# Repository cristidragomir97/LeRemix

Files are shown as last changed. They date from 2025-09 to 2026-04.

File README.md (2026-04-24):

# LLMy (leh·mee)

<p>
  <a href="https://opensource.org/licenses/MIT">
    
  </a>
  <a href="https://docs.ros.org/en/jazzy/">
    
  </a>
  <a href="http://gazebosim.org/">
    
  </a>
</p>

<p align="center">
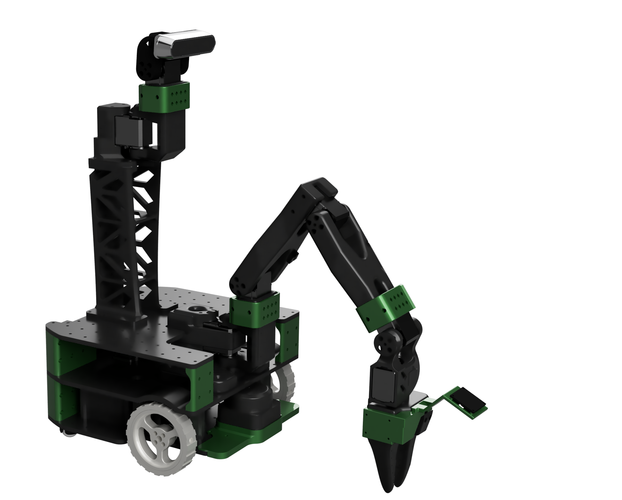
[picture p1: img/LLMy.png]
LLMy Robot
  
</p>

**LLMy** is a fully 3D-printed mobile manipulator built to be affordable, modular and ready to experiment with. 

| Component | Description |
|---|---|
| **Power** | 145W USB-C power bank with dual USB-PD triggers (12V) |
| **Compute** | Almost any SBC or Mini-PC under 75W |
| **Arm + Head** | 7× FEETECH ST3215 bus servos (6-DOF arm + 1-axis tilt) |
| **Drive** | 2× Waveshare DDSM210 direct-drive hub motors (differential) |
| **Bus Bridge** | [Axon](https://github.com/cristidragomir97/axon) — custom RP2350 PCB exposing the half-duplex servo bus, DDSM UART, RS485, CAN, and I²C over USB-CDC |
| **Perception** | RGB-D head camera and UVC wrist camera |
| **Localization** | RPLidar C1 (2D SLAM), wheel encoders, ICM-20948 IMU |

> 📋 **[Full BOM with sourcing links](docs/bom.md)** — includes camera options, SBC recommendations, and alternatives.

## 🏗️ Architecture

LLMy follows a modular ROS2 architecture that separates concerns between simulation, hardware interfaces, control, and user interaction. 

- **Hardware Abstraction**: The `ros2_control` framework provides a clean interface between high-level controllers (MoveIt2, Nav2) and low-level hardware, allowing the same code to run in both simulation and on real hardware.

- **Modular Sensors**: Each sensor system (cameras, IMU, LIDAR) is encapsulated in its own ROS2 package, publishing standardized messages that any application can consume. This makes it easy to swap sensors or add new ones without modifying application code.

- **Layered Control**: The control stack is separated into layers - from the motor manager nodes handling individual bus transactions, through the ros2_control plugin managing the hardware interface, up to high-level motion planning with MoveIt2 and navigation with Nav2.

- **Unified USB Bridge**: A single custom PCB ([Axon](https://github.com/cristidragomir97/axon)) consolidates every bus on the robot (half-duplex servo bus, DDSM UART, LIDAR UART, RS485, CAN, I²C) into one USB composite device. The SBC sees stable `/dev/axon-*` symlinks (via bundled udev rules) and each bus stays independent.

- **Simulation-First Development**: Gazebo integration allows safe development and testing before deploying to hardware. The same launch files and controllers work in both environments, reducing the simulation-to-reality gap.

```mermaid
graph TB

    subgraph "SBC (Jetson / Pi)"
        direction TB
        Control[🎛️ ros2_control]
        ControlPlugin[📦 llmy_control_plugin]
        St3215[📦 st3215_manager]
        Ddsm210[📦 ddsm210_manager]
        Nav[📦 llmy_nav · Nav2]
        Slam[📦 llmy_slam · slam_toolbox]
        MoveIt[📦 llmy_moveit · MoveIt 2]
        MCP[📦 llmy_mcp · MCP server]
        Teleop[📦 llmy_teleop_xbox]
        CameraNode[📦 llmy_camera]
        ImuNode[📦 llmy_imu]
        LidarNode[📦 rplidar]
    end

    subgraph "Axon USB Bridge (RP2350)"
        direction TB
        CdcMotor[CDC · half-duplex servo bus]
        CdcUart0[CDC · UART0 · DDSM bus]
        CdcUart1[CDC · UART1 · LIDAR]
    end

    subgraph "Actuators"
        Arm[6-DOF Arm · 6× ST3215]
        Tilt[Head Tilt · 1× ST3215]
        Wheels[Differential Drive · 2× DDSM210]
    end

    subgraph "Sensors"
        LIDAR[📏 RPLidar C1]
        HeadCamera[📷 RealSense D435i]
        WristCamera[📷 UVC wrist cam]
        IMU[📐 ICM-20948]
    end

    Teleop --> Control
    Nav --> Control
    MoveIt --> Control
    MCP <--> Control
    Slam --> Nav

    Control --> ControlPlugin
    ControlPlugin --> St3215
    ControlPlugin --> Ddsm210

    St3215 --> CdcMotor
    Ddsm210 --> CdcUart0

    CdcMotor --> Arm
    CdcMotor --> Tilt
    CdcUart0 --> Wheels

    LIDAR --> CdcUart1
    CdcUart1 --> LidarNode
    HeadCamera --> CameraNode
    WristCamera --> CameraNode
    IMU --> ImuNode

```

--- 

### 📦 ROS Packages

**Core Packages:**
- [**llmy_description**](ros/src/llmy_description/) - Robot URDF model with accurate kinematics and collision meshes
- [**llmy_control_plugin**](ros/src/llmy_control_plugin/) - ros2_control SystemInterface that bridges controllers to the motor-manager nodes over ROS topics
- [**llmy_control**](ros/src/llmy_control/) - Controller parameters, ros2_control configurations, hw/sim launch files
- [**st3215_manager**](ros/src/st3215_manager/) - Driver for FEETECH ST3215 servo groups (arm + head)
- [**ddsm210_manager**](ros/src/ddsm210_manager/) - Driver for Waveshare DDSM210 direct-drive wheel motors
- [**llmy_teleop_xbox**](ros/src/llmy_teleop_xbox/) - Xbox controller interface for manual driving + arm
- [**llmy_bringup**](ros/src/llmy_bringup/) - Top-level hardware bringup launch

**Navigation & SLAM:**
- [**llmy_nav**](ros/src/llmy_nav/) - Nav2 configuration and navigation mode management (mapping, navigation, mapfree, slam_nav)
- [**llmy_slam**](ros/src/llmy_slam/) - slam_toolbox configs for mapping and online SLAM

**Manipulation:**
- [**llmy_moveit**](ros/src/llmy_moveit/) - MoveIt 2 configuration for the 6-DOF arm (OMPL planning, KDL kinematics)

**Sensor & Vision:**
- [**llmy_camera**](ros/src/llmy_camera/) - RGB-D camera integration with depth-to-laser conversion
- [**llmy_imu**](ros/src/llmy_imu/) - IMU sensor fusion for orientation and navigation

**AI & Integration:**
- [**llmy_mcp**](ros/src/llmy_mcp/) - MCP (Model Context Protocol) server exposing ROS2 interfaces to LLMs

**Simulation:**
- [**llmy_gazebo**](ros/src/llmy_gazebo/) - Configurations and launch files for Gazebo simulation

**📋 [Detailed Package Documentation](docs/packages.md)**

## 🚀 Quick Start

### 🎮 Simulation (Fastest Way to Try LLMy!)

Get the robot running in Gazebo simulation in just a few commands:

```bash
# Clone and build the workspace
git clone https://github.com/cristidragomir97/llmy llmy_ws
cd llmy_ws/ros
vcs import src < repos.vcs
rosdep install --from-paths src --ignore-src -r -y
colcon build --symlink-install
source install/setup.bash

# Launch Gazebo simulation with controllers
ros2 launch llmy_gazebo gazebo.launch.py
```

The robot will spawn in Gazebo with all controllers active.

In a new terminal, start Xbox controller teleoperation:

```bash
ros2 launch llmy_teleop_xbox teleop_xbox.launch.py
```

**🎮 Xbox Controller Mapping:**
- **🏎️ Base Movement:** Right stick (forward/back + rotate)
- **🦾 Arm Control:**
  - **Joint 1:** RB (+) / LB (−)
  - **Joint 2:** RT (+) / LT (−)
  - **Joint 3:** Y (+) / A (−)
  - **Joint 4:** B (+) / X (−)
  - **Joint 5:** Start (+) / Back (−)
  - **Joint 6:** Right-stick click (+) / Left-stick click (−)
- **📷 Camera Tilt:** D-pad up/down

### 🏭 Hardware (via Forge)

LLMy on the real robot is deployed via [**Forge**](https://github.com/cristidragomir97/robocore-forge) — a lightweight deployment tool that takes a declarative `robot.yaml`, builds one Docker image per ROS component, and wires them together with a generated `docker-compose.<host>.yaml`. Each package (motion, SLAM, nav, camera, IMU, LIDAR, MCP, teleop, etc.) runs in its own container and communicates over a shared [Zenoh](https://zenoh.io/) router, so any single component can be rebuilt, restarted, or swapped without touching the rest.

The flow:

1. Edit `robot.yaml` — declare components, the packages each includes, the hardware devices each needs mounted, and the host it runs on.
2. `forge build` — one image per component, ready to push.
3. `forge deploy` — copies the generated compose file to the target and runs `docker compose up -d`.

Everything under `ros/src/` is plain ROS 2; Forge is just the packaging layer. You can bypass it entirely and run `colcon build` + `ros2 launch` on the SBC if you prefer bare metal.

### 📐 First-time calibration

Before commanding the arm, the servo encoder zeros need to match the URDF's zero pose. Walk through:

**📖 [Arm calibration guide](docs/arm-calibration.md)**

For general setup and troubleshooting:

**📖 [Getting Started Guide](docs/getting-started.md)**

---

--- 
## 🙏 Credits & Acknowledgments
This project stands on the shoulders of incredible open-source work:

- **[LeRobot Team](https://github.com/huggingface/lerobot)** - For pioneering accessible robotics and AI integration
- **[SIGRobotics-UIUC](https://github.com/SIGRobotics-UIUC)** - For their foundational work on LeKiwi
- **[Pavan Vishwanath](https://github.com/Pavankv92)** - ROS2 package development for [LeRobot SO-ARM101](https://github.com/Pavankv92/lerobot_ws)
- **[Gaotian Wang](https://github.com/Vector-Wangel/XLeRobot)** - For his amazing work on XLeRobot. Also for being kind enough to publish the STEP files for his robot upon request, files that were used to create the camera tower for LLMy. 

---
<div align="center">

<strong>⭐ Star this repo if LLMy helped you build something awesome! ⭐</strong>
</div>

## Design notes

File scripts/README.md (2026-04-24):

# LLMy Setup Scripts

Utility scripts for configuring and calibrating your LLMy robot.

## Scripts Overview

### 1. `set_servo_id.py` - Servo ID Configuration

Interactive tool for setting FEETECH STS3215 servo IDs one by one.

**Usage:**

```bash
# List all servos on the bus with telemetry
python3 set_servo_id.py --list

# Interactive mode - configure servos one by one
python3 set_servo_id.py

# Direct ID change
python3 set_servo_id.py --old-id 1 --new-id 5

# Custom serial port
python3 set_servo_id.py --port /dev/ttyACM0 --list
```

**LLMy ID Assignments:**
- Base (locomotion): IDs **1, 2, 3**
- Arm (manipulator): IDs **4, 5, 6, 7, 8, 9**
- Head (pan & tilt): IDs **10, 11**

**Workflow:**
1. Connect servos **one at a time** to avoid ID conflicts
2. Run interactive mode: `python3 set_servo_id.py`
3. For each servo:
   - Connect it to the bus
   - Script detects current ID
   - Enter desired new ID
   - Disconnect and connect next servo
4. Final verification scan shows all configured servos

---

### 2. `calibrate_arm.py` - Arm Calibration

Calibrates arm joint zero positions and movement limits.

**Usage:**

```bash
# Basic calibration (will prompt for save)
python3 calibrate_arm.py

# Auto-save to config file
python3 calibrate_arm.py --config ~/llmy_ws/ros/src/llmy_servo_manager/config/servo_manager.yaml

# Custom serial port
python3 calibrate_arm.py --port /dev/ttyUSB0
```

**⚠️ IMPORTANT:** Stop all ROS2 nodes before running calibration!

```bash
# Kill any running servo manager nodes
pkill -f servo_manager
```

**Calibration Process:**

1. **Zero Position Setup:**
   - Position arm fully erect (vertical)
   - Close gripper completely
   - Center wrist rotation
   - Script records zero positions

2. **Joint Limit Calibration:**
   - For each of 6 arm joints:
     - Move joint to minimum position → record
     - Move joint to maximum position → record
   - Script validates and saves limits

3. **Verification:**
   - Arm returns to zero position
   - Summary table shows all calibration data
   - Option to save to YAML config

**Output Example:**
```
┌─────────────────────────┬──────┬──────────┬─────────┬─────────┐
│ Joint                   │  ID  │ Zero Pos │ Min Pos │ Max Pos │
├─────────────────────────┼──────┼──────────┼─────────┼─────────┤
│ Joint 1 (Base Rotation) │   4  │  2048    │   512   │  3584   │
│ Joint 2 (Shoulder)      │   5  │  2048    │   768   │  3328   │
...
```

**What Gets Saved:**

The calibration tool updates `servo_manager.yaml` with:
- `arm_zero_positions`: Reference position for each joint (6 values)
- `arm_min_limits`: Minimum safe position in ticks (6 values)
- `arm_max_limits`: Maximum safe position in ticks (6 values)

These limits are automatically enforced by the servo manager to prevent damage.

---

## Prerequisites

### Hardware Setup
- Robot powered on (12V to servos)
- Serial connection established (USB or UART)
- Correct serial port identified

### Software Requirements
```bash
# Install st3215 Python library
pip install st3215

# Install PyYAML for config management
pip install pyyaml
```

### Permissions
```bash
# Add your user to dialout group for serial access
sudo usermod -a -G dialout $USER
# Log out and back in for changes to take effect
```

---

## Common Serial Ports

| Platform | Port | Description |
|---|---|---|
| Raspberry Pi | `/dev/ttyUSB0` | USB adapter |
| Jetson Nano/Orin | `/dev/ttyTHS1` | Hardware UART |
| Generic Linux | `/dev/ttyACM0` | USB CDC adapter |
| Waveshare adapter | `/dev/ttyUSB0` | FT232 USB-Serial |

**Find your port:**
```bash
# List all serial devices
ls /dev/tty{USB,ACM,THS}* 2>/dev/null

# Monitor kernel messages when plugging in
dmesg | tail
```

---

## Workflow: Full Robot Setup

**Complete setup from scratch:**

```bash
# 1. Set all servo IDs (connect one at a time)
cd ~/llmy_ws/scripts
python3 set_servo_id.py

# 2. Verify all servos are detected
python3 set_servo_id.py --list

# 3. Calibrate arm joints
python3 calibrate_arm.py --config ../ros/src/llmy_servo_manager/config/servo_manager.yaml

# 4. Build and launch ROS workspace
cd ~/llmy_ws/ros
colcon build
source install/setup.bash
ros2 launch llmy_bringup bringup_robot.launch.py
```

---

## Troubleshooting

### Script can't connect to servos
```bash
# Check port exists
ls -l /dev/ttyUSB0

# Check permissions
groups  # Should show 'dialout'

# Try different baud rates
python3 set_servo_id.py --baud 115200
```

### Servo not responding during calibration
- Ensure 12V power supply is connected
- Check servo cables are properly seated
- Verify servo ID matches expected value
- Try power cycling the servo

### Calibration data not saving
- Verify config file path is correct
- Check file permissions (must be writable)
- Review backup file (.backup) for changes
- Manually inspect YAML syntax

### ROS node conflicts
```bash
# Kill all servo-related processes
pkill -f servo_manager
pkill -f llmy

# Verify no nodes running
ros2 node list
```

---

## Advanced Usage

### Batch ID Configuration
```bash
# Script for setting multiple servos
for id in {1..11}; do
  echo "Connect servo for ID $id and press enter..."
  read
  python3 set_servo_id.py --old-id 1 --new-id $id
done
```

### Custom Calibration Workflow
```python
# Manual calibration via Python API
from st3215 import ST3215

servo = ST3215('/dev/ttyUSB0')
pos = servo.ReadPosition(4)  # Read joint 1 position
print(f"Current position: {pos} ticks")
```

### Verify Limits Are Enforced
```bash
# After calibration, test limit enforcement
ros2 topic pub /motor_manager/arm_cmd std_msgs/msg/Float64MultiArray "data: [10.0, 0, 0, 0, 0, 0]"
# Joint should clamp to max limit, not attempt invalid position
```

---

## Support

For issues or questions:
- GitHub Issues: https://github.com/cristidragomir97/llmy/issues
- Documentation: [docs/getting-started.md](../docs/getting-started.md)

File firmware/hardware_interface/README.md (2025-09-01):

# Simple MicroROS Servo Driver

A simplified, barebones version of the microros_servo_driver with only essential functionality.

## Features

- ✅ MicroROS communication
- ✅ Servo control (arm and base servos)
- ✅ Joint state publishing
- ✅ Serial debugging output
- ❌ No display/OLED support
- ❌ No button input handling
- ❌ No watchdog functionality
- ❌ Minimal dependencies

## Hardware Requirements

- ESP32 development board
- Servo communication via GPIO 18 (RX) and GPIO 19 (TX)
- Serial connection for debugging and MicroROS communication

## Configuration

All servo calibration and hardware settings are defined in `src/config.h`.

## Build and Upload

This project uses PlatformIO:

```bash
# Build the project
pio run

# Upload to ESP32
pio run --target upload

# Monitor serial output
pio device monitor
```

## Dependencies

- MicroROS PlatformIO library
- SCServo library for servo communication

## Usage

1. Flash the firmware to your ESP32
2. Connect via serial at 115200 baud
3. The device will automatically connect to MicroROS and start listening for commands
4. Servos are enabled by default

## Topics

- `/esp32/base_cmd` - Base motor commands (Float64MultiArray)
- `/esp32/arm_cmd` - Arm joint commands (Float64MultiArray) 
- `/esp32/joint_states` - Joint state feedback (JointState)

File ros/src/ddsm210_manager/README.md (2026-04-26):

# ddsm210_manager

ROS2 driver for Waveshare DDSM210 direct drive servo motors. Includes a from-scratch serial protocol implementation — no external motor library required.

## Quick Start

```bash
colcon build --packages-select ddsm210_manager

ros2 launch ddsm210_manager ddsm210.launch.py

# Custom config
ros2 launch ddsm210_manager ddsm210.launch.py config_file:=/path/to/config.yaml
```

## Hardware

- **Motor**: Waveshare DDSM210 (integrated brushless motor + encoder + FOC driver)
- **Interface**: UART (TX, RX, GND, VCC)
- **Baud**: 115200, 8N1
- **Voltage**: 11-22V DC
- **Speed**: -210..210 RPM
- **Encoder**: 4096 resolution (relative), 65536 ticks/rev (position feedback)

## Protocol

The driver implements the full DDSM210 UART protocol (10-byte frames, CRC-8/MAXIM):

| Protocol | Command | Description |
|---|---|---|
| 1 (0x64) | Drive | Set velocity/position, get speed+position+temp feedback |
| 2 (0x74) | Odometry | Get mileage laps (continuous) + absolute position |
| 3 (0xA0) | Set Mode | Open loop (0x00), velocity loop (0x02), position loop (0x03) |
| 4 | Set ID | Change motor ID (send 5x, one motor on bus) |
| 5 (0x75) | Query Mode | Get current operating mode |

## Wiring: Multi-Motor Setup

The DDSM210 uses separate TX/RX UART lines. When connecting multiple motors, their TX outputs will conflict if wired together directly. Two options:

**Option 1 — Separate ports (recommended for direct wiring):**
Each motor gets its own USB-to-UART adapter. Configure `ports` with one entry per motor:
```yaml
ports: ["/dev/ttyUSB0", "/dev/ttyUSB1"]
motor_ids: [1, 2]
```

**Option 2 — Shared bus (requires AND gates):**
Use a bus board like the Waveshare DDSM Driver HAT, which combines motor TX lines through AND gates (SN74LVC1G08). Configure a single port:
```yaml
ports: ["/dev/ttyUSB0"]
motor_ids: [1, 2]
```

## Configuration

| Parameter | Type | Default | Description |
|---|---|---|---|
| `ports` | string[] | `["/dev/ttyUSB0"]` | Serial port(s) — one per motor, or one shared by all |
| `baud` | int | `115200` | Baud rate |
| `command_rate` | float | `50.0` | Command send rate (Hz) |
| `telemetry_rate` | float | `50.0` | JointState publish rate (Hz) |
| `joint_states_topic` | string | `/motor_manager/joint_states` | JointState output topic |
| `command_topic` | string | `/motor_manager/base_cmd` | Float64MultiArray command input topic |
| `total_joints` | int | `0` | JointState array size (0 = auto from state_indices) |
| `mode` | string | `velocity` | `velocity` or `position` |
| `accel_time` | int | `0` | Acceleration per 1 RPM in 0.1ms units |
| `motor_ids` | int[] | `[1, 2]` | Motor IDs on the bus |
| `joint_names` | string[] | `[right_wheel_joint, left_wheel_joint]` | Joint names for JointState |
| `direction` | int[] | `[1, -1]` | Per-motor direction multiplier |
| `command_indices` | int[] | `[0, 1]` | Which indices to read from incoming command array |
| `state_indices` | int[] | `[0, 1]` | Which indices to write in JointState arrays |
| `speed_scale` | float | `1.0` | Multiplier applied to incoming velocity commands |

## Sharing the JointState Topic

This package publishes JointState to the same topic as the `st3215_servo_manager`. Each package fills in its own `state_indices` slots:

```
DDSM210 (wheels):     state_indices: [0, 1]
ST3215 (arm+camera):  state_indices: [2, 3, 4, 5, 6, 7, 8]
```

Both publish to `/motor_manager/joint_states`. Consumers match by joint name.

## Low-Level API

The `ddsm210.py` module can be used standalone without ROS:

```python
from ddsm210_manager.ddsm210 import DDSM210, MODE_VELOCITY

motor = DDSM210("/dev/ttyUSB0")
motor.set_mode(1, MODE_VELOCITY)
motor.set_velocity(1, 500)   # 50 RPM
motor.brake(1)
odom = motor.get_odometry(1) # {'mileage_laps': ..., 'position': ..., 'error_code': ...}
motor.close()
```

## Interactive Terminal

Test motors without ROS using the built-in terminal:

```bash
# Single port
python3 scripts/test_motor.py --port /dev/ttyUSB0

# Two ports (one per motor)
python3 scripts/test_motor.py --port /dev/ttyUSB0 --port /dev/ttyUSB1
```

Commands: `scan`, `ping`, `speed`, `brake`, `odom`, `mode`, `pos`, `set_id`, `query_id`, `ports`, `quit`.

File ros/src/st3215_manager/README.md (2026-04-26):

# st3215_manager

Generic, config-driven ROS2 driver for FEETECH ST3215 servo motors. Define motor groups in YAML — no code changes needed to add motors or support a new robot.

## Quick Start

```bash
# Build
colcon build --packages-select st3215_manager

# Launch with default config
ros2 launch st3215_manager servo_manager.launch.py

# Launch with a custom config
ros2 launch st3215_manager servo_manager.launch.py \
  config_file:=/path/to/your/config.yaml
```

## Configuration

All configuration lives in a single YAML file. See `config/servo_manager.yaml` for the LLMy default and `config/so101_arm.yaml` for a standalone SO-101 arm example.

### Global Parameters

| Parameter | Type | Default | Description |
|---|---|---|---|
| `port` | string | `/dev/ttyTHS1` | Serial port for the Feetech bus |
| `baud` | int | `1000000` | Baud rate |
| `ticks_per_rev` | int | `4096` | Encoder ticks per revolution |
| `telemetry_rate` | float | `50.0` | Joint state publish rate (Hz) |
| `joint_states_topic` | string | `/motor_manager/joint_states` | Topic for JointState output |
| `total_joints` | int | `0` | Size of JointState arrays. Set to `0` to auto-calculate from highest `state_index + 1` |
| `brake_method` | string | `torque_disable` | `torque_disable`, `velocity_ramp`, or `position_brake` |
| `velocity_ramp_time` | float | `0.1` | Ramp time for velocity_ramp brake (s) |
| `brake_acceleration` | int | `100` | Acceleration for position_brake method |
| `motor_telemetry_enable` | bool | `false` | Publish per-motor current/voltage/load/temperature |
| `motor_telemetry_rate` | float | `10.0` | Per-motor telemetry rate (Hz) |
| `test_on_startup` | bool | `false` | Run motor test sequences on startup |
| `group_names` | string[] | `["base"]` | List of motor group names to load |

### Motor Group Parameters

Each entry in `group_names` becomes a parameter prefix. For a group named `arm`, the parameters are `arm.enable`, `arm.mode`, etc.

| Parameter | Type | Default | Description |
|---|---|---|---|
| `<name>.enable` | bool | `true` | Enable this group |
| `<name>.mode` | string | `velocity` | `velocity` or `position` |
| `<name>.topic` | string | `/motor_manager/<name>_cmd` | ROS topic to subscribe for commands |
| `<name>.motor_ids` | int[] | `[]` | ST3215 motor IDs on the bus |
| `<name>.joint_names` | string[] | `[]` | Joint names for JointState messages |
| `<name>.direction` | int[] | `[]` | Per-motor direction multiplier (`1` or `-1`) |
| `<name>.command_indices` | int[] | `[]` | Which indices in the incoming `Float64MultiArray` to read from |
| `<name>.state_indices` | int[] | `[]` | Which indices in the outgoing `JointState` arrays to write to |
| `<name>.speed_scale` | float | `1.0` | Speed multiplier applied to incoming commands |
| `<name>.accel` | int[] | `[]` | Per-motor acceleration (0-255, lower = smoother) |
| `<name>.unwrap_position` | bool | `false` | Track continuous rotation (needed for wheels/odometry) |
| `<name>.position_speed` | int | `200` | Base speed for position-mode MoveTo commands |
| `<name>.position_accel` | int | `200` | Base accel for position-mode MoveTo commands |

All per-motor arrays (`motor_ids`, `joint_names`, `direction`, `command_indices`, `state_indices`, `accel`) must have the same length.

### Index Mapping

`command_indices` and `state_indices` decouple the motor ordering from message layout:

- **`command_indices`**: Motor `i` reads its command from `msg.data[command_indices[i]]`. This allows the incoming array to contain joints from other packages, or to reorder joints without changing motor wiring.

- **`state_indices`**: Motor `i` writes its state to `JointState.position[state_indices[i]]`. This lets multiple packages publish to the same topic with non-overlapping indices.

#### Example: Shared topic with another motor driver

If a DSSM210 driver handles wheels at indices 0-1, and this package handles the arm at indices 2-7:

```yaml
total_joints: 8   # wheels (0,1) + arm (2-7)

arm:
  motor_ids: [3, 4, 5, 6, 7, 8]
  command_indices: [0, 1, 2, 3, 4, 5]   # arm topic only has arm joints
  state_indices: [2, 3, 4, 5, 6, 7]     # slots 0-1 reserved for wheels
```

The DSSM210 package would publish wheels at indices 0-1 on the same `joint_states_topic`. Consumers match by joint name, and the fixed indices ensure a predictable array layout.

## Topics

### Subscribed (one per enabled group)

Configured via `<group>.topic`. Expects `std_msgs/Float64MultiArray`.

### Published

| Topic | Type | Description |
|---|---|---|
| `<joint_states_topic>` | `sensor_msgs/JointState` | Joint positions and velocities |
| `/motor_telemetry/<joint_name>/current` | `std_msgs/Float32` | Motor current (mA) |
| `/motor_telemetry/<joint_name>/voltage` | `std_msgs/Float32` | Motor voltage (V) |
| `/motor_telemetry/<joint_name>/load` | `std_msgs/Float32` | Motor load (%) |
| `/motor_telemetry/<joint_name>/temperature` | `std_msgs/Int32` | Motor temperature (C) |

Motor telemetry topics are only created when `motor_telemetry_enable: true`.

## Adding a New Robot

1. Copy `config/so101_arm.yaml` as a starting point
2. Set `port` to your serial device
3. Define your motor groups with IDs, joint names, and indices
4. Launch with `config_file:=/path/to/your/config.yaml`

No code changes required.

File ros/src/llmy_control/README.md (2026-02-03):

# llmy_control

Controller configurations and launch files for the LLMy robot's motion subsystem. Manages differential drive, 6-DOF arm, and pan-tilt head through ros2_control.

## Launch Files

| Launch File | Description |
|---|---|
| `motion.launch.py` | Main entry point — launches servo manager + control stack |
| `control_stack.launch.py` | Robot state publisher, controller manager, controller spawners, twist_mux |
| `base_systems.launch.py` | Servo manager for low-level motor communication |

```bash
# Full motion subsystem
ros2 launch llmy_control motion.launch.py

# Control stack only (servo manager already running)
ros2 launch llmy_control control_stack.launch.py
```

## Config Files

| File | Description |
|---|---|
| `controllers.hw.yaml` | Hardware controller definitions (50Hz, real hardware) |
| `controllers.sim.yaml` | Simulation controller definitions (100Hz, sim time) |
| `twist_mux.yaml` | Velocity multiplexer — xbox (pri 50), mcp (pri 30), nav (pri 10) |
| `ros2_control_bridge.yaml` | Hardware interface plugin config for servo_manager topics |

## Controllers

| Controller | Type | State |
|---|---|---|
| `joint_state_broadcaster` | JointStateBroadcaster | Active |
| `diff_drive_controller` | DiffDriveController | Active |
| `arm_controller` | JointGroupPositionController | Active |
| `arm_trajectory_controller` | JointTrajectoryController | Inactive (for MoveIt) |
| `head_controller` | JointGroupPositionController | Active |

Switch to trajectory control for MoveIt:
```bash
ros2 control switch_controller --activate arm_trajectory_controller --deactivate arm_controller
```

## URDF

`urdf/LLMy.hardware.xacro` defines the ros2_control hardware interface using the `llmy_control_plugin/ROS2ControlBridge` plugin, which communicates with the servo manager via ROS topics.

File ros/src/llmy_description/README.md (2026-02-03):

# llmy_description

Complete URDF/Xacro robot model for the LLMy mobile manipulator. Provides the "digital twin" used by all other packages for visualization, simulation, and control.

## Robot Structure

- **Base**: Differential drive with 2 powered wheels + 2 passive casters
- **Arm**: 6-DOF (joints 1-6) — base rotation, shoulder, elbow, two wrist joints, gripper
- **Head**: Pan-tilt camera mount with 2 servos
- **Sensors**: RealSense RGB-D (head), USB camera (wrist), RPLidar, IMU

## Launch Files

```bash
# Visualize the robot model in RViz (standalone)
ros2 launch llmy_description display.launch.py

# Spawn in Gazebo (usually called by llmy_gazebo instead)
ros2 launch llmy_description gazebo.launch.py
```

## Key Files

| File | Description |
|---|---|
| `urdf/LLMy.xacro` | Main robot model — all links, joints, and sensor frames |
| `urdf/materials.xacro` | Material definitions |
| `urdf/LLMy.gazebo` | Gazebo-specific physics and sensor plugins |
| `urdf/LLMy.ros2control` | ros2_control interfaces for simulation |
| `meshes/*.stl` | 48 STL mesh files for visualization and collision |
| `config/display.rviz` | RViz visualization preset |

## Xacro Arguments

| Argument | Default | Description |
|---|---|---|
| `use_sim` | `false` | Load Gazebo ros2_control plugin when `true`, hardware plugin when `false` |

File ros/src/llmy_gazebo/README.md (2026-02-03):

# llmy_gazebo

Gazebo Harmonic simulation environment for the LLMy robot. Spawns the robot with all controllers, sensor bridges, and a furnished apartment world.

## Launch

```bash
# Launch simulation (default: sticky_floor apartment world)
ros2 launch llmy_gazebo gazebo.launch.py

# Empty world
ros2 launch llmy_gazebo gazebo.launch.py world:=empty.sdf
```

## What Gets Launched

1. Robot URDF loaded via xacro (`use_sim:=true`)
2. Gazebo simulation with world file
3. ROS-Gazebo bridges for sensors (lidar, IMU, cameras, clock)
4. Controller spawners: `joint_state_broadcaster`, `diff_drive_controller`, `arm_controller`, `head_controller`
5. `arm_trajectory_controller` loaded inactive (for MoveIt)
6. `twist_mux` for velocity command arbitration

## World Files

| World | Description |
|---|---|
| `sticky_floor.world` | Furnished apartment (~15x12m) with walls, furniture, and obstacles |
| `empty.sdf` | Minimal ground plane with lighting |

## Bridged Topics

| Topic | Type | Direction |
|---|---|---|
| `/scan` | LaserScan | Gazebo -> ROS |
| `/sensors/imu` | Imu | Gazebo -> ROS |
| `/head_camera/rgb/*` | Image + CameraInfo | Gazebo -> ROS |
| `/head_camera/depth/*` | Image + CameraInfo | Gazebo -> ROS |
| `/wrist_camera/rgb/*` | Image + CameraInfo | Gazebo -> ROS |
| `/clock` | Clock | Gazebo -> ROS |

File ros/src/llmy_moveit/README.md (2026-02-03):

# llmy_moveit

MoveIt 2 configuration for the LLMy robot's 6-DOF arm (SO-ARM101) and gripper. Provides collision-free trajectory planning, inverse kinematics, and integration with the ros2_control trajectory controller.

## Launch

```bash
# Hardware
ros2 launch llmy_moveit moveit.launch.py

# Simulation
ros2 launch llmy_moveit moveit.launch.py use_sim_time:=true

# Without RViz
ros2 launch llmy_moveit moveit.launch.py launch_rviz:=false
```

## Prerequisites

The control stack must already be running. MoveIt uses `arm_trajectory_controller`, which is loaded inactive by default. Activate it:

```bash
ros2 control switch_controller --activate arm_trajectory_controller --deactivate arm_controller
```

## Planning Groups

| Group | Joints | Description |
|---|---|---|
| `arm` | 1, 2, 3, 4, 5 | Kinematic chain from base to gripper |
| `gripper` | 6 | Gripper open/close |

## Named Poses

| Pose | Description |
|---|---|
| `home` | All joints at zero |
| `open` | Gripper fully open |
| `closed` | Gripper closed |

## Config Files

| File | Description |
|---|---|
| `llmy.srdf` | Planning groups, named poses, collision disable pairs |
| `kinematics.yaml` | KDL solver (0.005 resolution, 0.05s timeout) |
| `joint_limits.yaml` | Velocity/acceleration limits and scaling factors |
| `ompl_planning.yaml` | OMPL planners: RRTConnect, RRT, PRM |
| `moveit_controllers.yaml` | Maps MoveIt to ros2_control controllers |

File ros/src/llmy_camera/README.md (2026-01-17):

# llmy_camera

Camera integration package for the LLMy robot, providing both a head-mounted RealSense RGB-D camera and a wrist-mounted USB camera with compressed image transport and laser scan conversion capabilities.

## Overview

The llmy_camera package manages two camera systems:
- **Head Camera**: Intel RealSense RGB-D camera (D435i, D455, etc.) mounted on the pan/tilt head
- **Wrist Camera**: USB camera (640x480) mounted on the end-effector for close-up manipulation tasks

## Launch Files

### `camera.launch.py`

Main launch file that brings up both camera systems with full feature set:

**Components:**
- RealSense RGB-D camera (head_camera namespace)
- USB wrist camera (wrist_camera namespace)
- Compressed image transport for both cameras
- Depth-to-laser-scan conversion for navigation

```bash
# Launch both cameras with all features
ros2 launch llmy_camera camera.launch.py

# Launch without wrist camera
ros2 launch llmy_camera camera.launch.py enable_wrist_camera:=false

# Launch without laser scan conversion
ros2 launch llmy_camera camera.launch.py enable_laser_scan:=false

# Disable compressed transport
ros2 launch llmy_camera camera.launch.py enable_compressed:=false
```

### `realsense_only.launch.py`

Minimal launch file for RealSense camera only (no wrist camera, no laser scan, no compression):

```bash
# Launch only RealSense camera
ros2 launch llmy_camera realsense_only.launch.py

# Specify device type
ros2 launch llmy_camera realsense_only.launch.py device_type:=d435i
```

## Launch Arguments

### `camera.launch.py` Arguments

| Argument | Default | Description |
|---|---|---|
| `camera_name` | `head_camera` | RealSense camera name |
| `device_type` | `` | RealSense device type (auto-detect if empty) |
| `enable_wrist_camera` | `true` | Enable USB wrist camera |
| `wrist_camera_device` | `/dev/video0` | Video device path for wrist camera |
| `enable_compressed` | `true` | Enable compressed image transport |
| `enable_laser_scan` | `true` | Enable depth to laser scan conversion |
| `laser_scan_min_height` | `-0.5` | Minimum height for laser scan slice (m) |
| `laser_scan_max_height` | `0.5` | Maximum height for laser scan slice (m) |
| `laser_scan_angle_min` | `-1.57` | Minimum scan angle (-90°) |
| `laser_scan_angle_max` | `1.57` | Maximum scan angle (+90°) |
| `laser_scan_angle_increment` | `0.005` | Angular resolution |
| `laser_scan_range_min` | `0.2` | Minimum range (m) |
| `laser_scan_range_max` | `10.0` | Maximum range (m) |

### `realsense_only.launch.py` Arguments

| Argument | Default | Description |
|---|---|---|
| `camera_name` | `camera` | RealSense camera name |
| `device_type` | `d435i` | RealSense device type |

## Topics Published

### Head Camera (RealSense)

**Color Stream:**
- `/head_camera/head_camera/color/image_raw` - Raw color image (640x480@30Hz)
- `/head_camera/head_camera/color/image_compressed` - Compressed color image (JPEG)
- `/head_camera/head_camera/color/camera_info` - Camera calibration

**Depth Stream:**
- `/head_camera/head_camera/depth/image_rect_raw` - Rectified depth image
- `/head_camera/head_camera/depth/camera_info` - Depth camera calibration

**Laser Scan:**
- `/scan` - 2D laser scan converted from depth (for navigation)

### Wrist Camera (USB)

- `/wrist_camera/image_raw` - Raw wrist camera image (640x480@30Hz)
- `/wrist_camera/image_compressed` - Compressed wrist image (JPEG)
- `/wrist_camera/camera_info` - Camera calibration

## Supported Hardware

### RealSense Cameras
- Intel RealSense D435i (recommended)
- Intel RealSense D455
- Intel RealSense L515
- Other RealSense RGB-D cameras

### Wrist Camera
- Any UVC-compatible USB camera
- Default: 640x480@30fps, MJPEG format

## Usage Examples

### View Camera Streams

```bash
# View head camera color stream
ros2 run rqt_image_view rqt_image_view /head_camera/head_camera/color/image_raw

# View head camera depth
ros2 run rqt_image_view rqt_image_view /head_camera/head_camera/depth/image_rect_raw

# View wrist camera
ros2 run rqt_image_view rqt_image_view /wrist_camera/image_raw

# View compressed images (bandwidth efficient)
ros2 run rqt_image_view rqt_image_view /head_camera/head_camera/color/image_compressed/compressed
ros2 run rqt_image_view rqt_image_view /wrist_camera/image_compressed/compressed
```

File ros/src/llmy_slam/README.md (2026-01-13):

# llmy_slam

SLAM (Simultaneous Localization and Mapping) integration for the LLMy robot using [slam_toolbox](https://github.com/SteveMacenski/slam_toolbox).

This package provides custom launch files and configurations specifically tailored for the LLMy robot's hardware setup.

## Overview

This package wraps slam_toolbox with LLMy-specific configurations for:
- **Sensor input**: RPLidar on `/scan` topic
- **Odometry**: Omnidirectional controller publishing `/omnidirectional_controller/odom` and TF `odom` → `base_link`
- **Base frame**: `base_link`
- **Map frame**: `map`

## Prerequisites

1. **Install slam_toolbox**:
   ```bash
   sudo apt install ros-${ROS_DISTRO}-slam-toolbox
   ```

2. **Ensure RPLidar is publishing** on `/scan` topic:
   - Enable RPLidar in your bringup configuration
   - Or use depth-to-laserscan from the RealSense camera

3. **Verify odometry is being published**:
   ```bash
   ros2 topic echo /omnidirectional_controller/odom
   ```

   Note: slam_toolbox uses TF transforms (`odom` → `base_link`) rather than subscribing to the odometry topic directly.

## Usage

### 1. Mapping Mode (Creating a Map)

Launch slam_toolbox in online asynchronous mapping mode:

```bash
ros2 launch llmy_slam online_async_launch.py
```

**Options:**
- `use_sim_time:=true` - Use simulation time (for Gazebo)
- `params_file:=/path/to/custom/params.yaml` - Use custom parameters

**While mapping:**
- Drive the robot around using teleop or xbox controller
- The map will be built in real-time
- You can view the map in RViz by adding the `/map` topic

**To save the map:**

Use the slam_toolbox service:
```bash
ros2 service call /slam_toolbox/save_map slam_toolbox/srv/SaveMap "{name: {data: '/path/to/your/map_name'}}"
```

This will create two files:
- `map_name.posegraph` - SLAM graph data
- `map_name.data` - Serialized map data

### 2. Localization Mode (Using a Pre-built Map)

Once you have a saved map, you can use it for localization only:

1. **Update the map path** in `config/mapper_params_localization.yaml`:
   ```yaml
   map_file_name: /path/to/your/saved/map_name
   ```

2. **Launch localization**:
   ```bash
   ros2 launch llmy_slam localization_launch.py
   ```

In this mode, the robot will localize itself within the existing map without modifying it.

### 3. Lifelong Mode (Dynamic Mode Switching) ⭐ **Recommended**

Lifelong mode is the most flexible approach, allowing you to **dynamically switch between mapping and localization** using ROS services without restarting the node.

**Launch lifelong mode:**
```bash
ros2 launch llmy_slam lifelong_launch.py
```

**Options:**
- `use_sim_time:=true` - Use simulation time (for Gazebo)
- `params_file:=/path/to/custom/params.yaml` - Use custom parameters

#### Dynamic Mode Switching with Services

Once running, you can control the SLAM behavior using these services:

**1. Pause Mapping (Switch to Localization Mode):**
```bash
ros2 service call /slam_toolbox/pause_new_measurements std_srvs/srv/SetBool "{data: true}"
```

**2. Resume Mapping:**
```bash
ros2 service call /slam_toolbox/pause_new_measurements std_srvs/srv/SetBool "{data: false}"
```

**3. Save the Current Map (while running):**
```bash
ros2 service call /slam_toolbox/serialize_map slam_toolbox/srv/SerializePoseGraph "{filename: '/path/to/map_name'}"
```

**4. Load an Existing Map (while running):**
```bash
ros2 service call /slam_toolbox/deserialize_map slam_toolbox/srv/DeserializePoseGraph "{filename: '/path/to/map_name', match_type: 2}"
```
- `match_type: 1` - Start at the origin of the loaded map
- `match_type: 2` - Start at the current position (relocalize in the map)

**5. Clear the Current Queue:**
```bash
ros2 service call /slam_toolbox/clear_queue std_srvs/srv/Empty
```

#### Example Workflow with Lifelong Mode

```bash
# 1. Launch lifelong SLAM
ros2 launch llmy_slam lifelong_launch.py

# 2. Drive around and build a map
# ... (use teleop/xbox controller)

# 3. Save the map
ros2 service call /slam_toolbox/serialize_map slam_toolbox/srv/SerializePoseGraph \
  "{filename: '/home/user/maps/office_map'}"

# 4. Switch to localization mode (pause mapping)
ros2 service call /slam_toolbox/pause_new_measurements std_srvs/srv/SetBool "{data: true}"

# 5. Later, resume mapping to update the map
ros2 service call /slam_toolbox/pause_new_measurements std_srvs/srv/SetBool "{data: false}"

# 6. Or load a different map entirely
ros2 service call /slam_toolbox/deserialize_map slam_toolbox/srv/DeserializePoseGraph \
  "{filename: '/home/user/maps/warehouse_map', match_type: 2}"
```

#### Advantages of Lifelong Mode

- **No restarts needed** - Switch modes on the fly
- **Flexible workflows** - Map, localize, then continue mapping
- **Multi-session mapping** - Save and continue mapping across multiple sessions
- **Hot-swapping maps** - Load different maps without stopping the node

## Configuration Files

### `config/mapper_params_lifelong.yaml`
Configuration for lifelong mode with dynamic behavior:
- Supports both mapping and localization
- Can load existing maps and continue mapping
- Full service interface for dynamic control
- Recommended for production deployments

### `config/mapper_params_online_async.yaml`
Configuration for online mapping mode. Key parameters:
- `scan_topic: /scan` - Laser scan input
- `odom_frame: odom` - Odometry frame
- `base_frame: base_link` - Robot base frame
- `map_frame: map` - Map frame
- `max_laser_range: 12.0` - RPLidar typical max range
- `resolution: 0.05` - Map resolution (5cm per pixel)
- `minimum_travel_distance: 0.2` - Minimum movement before updating (meters)

### `config/mapper_params_localization.yaml`
Configuration for localization mode. Similar to mapping mode but with:
- `mode: localization` - Only localizes, doesn't update map
- `map_file_name: /path/to/map` - Path to pre-built map

## RViz Visualization

To visualize SLAM in RViz:

1. Launch RViz:
   ```bash
   rviz2
   ```

2. Add the following displays:
   - **TF** - To see coordinate frames
   - **Map** - Topic: `/map`
   - **LaserScan** - Topic: `/scan`
   - **RobotModel** - Uses the URDF description

3. Set **Fixed Frame** to `map`

## Integration with LLMy Bringup

To automatically start SLAM with your robot, you can include this launch file in `llmy_bringup`:

```python
from launch.actions import IncludeLaunchArgument, IncludeLaunchDescription
from launch.launch_description_sources import PythonLaunchDescriptionSource
from launch.substitutions import LaunchConfiguration

# Option 1: Lifelong mode (recommended for flexibility)
slam_launch = IncludeLaunchDescription(
    PythonLaunchDescriptionSource(
        PathJoinSubstitution([
            FindPackageShare('llmy_slam'),
            'launch',
            'lifelong_launch.py'
        ])
    )
)

# Option 2: Online mapping mode (simpler, mapping only)
# slam_launch = IncludeLaunchDescription(
#     PythonLaunchDescriptionSource(
#         PathJoinSubstitution([
#             FindPackageShare('llmy_slam'),
#             'launch',
#             'online_async_launch.py'
#         ])
#     )
# )
```

## Topics

### Subscribed:
- `/scan` (sensor_msgs/LaserScan) - Laser scan from RPLidar
- `/tf` - Transform tree (requires `odom` → `base_link` transform)
- `/tf_static` - Static transforms

**Note**: slam_toolbox does not subscribe to `/omnidirectional_controller/odom` directly. It uses the TF transform `odom` → `base_link` published by the omnidirectional controller.

### Published:
- `/map` (nav_msgs/OccupancyGrid) - Generated map
- `/tf` - Publishes `map` → `odom` transform

## Services

slam_toolbox provides many useful services:

### Core Services

- `/slam_toolbox/pause_new_measurements` - **Pause/resume mapping** (switch to localization mode)
- `/slam_toolbox/serialize_map` - **Save map to file** (posegraph format)
- `/slam_toolbox/deserialize_map` - **Load map from file** and optionally relocalize
- `/slam_toolbox/save_map` - Save map as standard ROS map format (.pgm + .yaml)
- `/slam_toolbox/clear_queue` - Clear the scan queue

### Additional Services

- `/slam_toolbox/toggle_interactive_mode` - Enable/disable interactive markers in RViz
- `/slam_toolbox/clear` - Clear the current graph (start fresh)
- `/slam_toolbox/dynamic_map` - Get the current map
- `/slam_toolbox/manual_loop_closure` - Manually trigger loop closure

List all available services:
```bash
ros2 service list | grep slam_toolbox
```

Get service details:
```bash
ros2 service type /slam_toolbox/pause_new_measurements
ros2 interface show std_srvs/srv/SetBool
```

### Quick Service Reference

**Save map (posegraph format, can be loaded back):**
```bash
ros2 service call /slam_toolbox/serialize_map slam_toolbox/srv/SerializePoseGraph \
  "{filename: '/home/user/maps/my_map'}"
```

**Save map (standard ROS format, for navigation stack):**
```bash
ros2 service call /slam_toolbox/save_map slam_toolbox/srv/SaveMap \
  "{name: {data: '/home/user/maps/my_map'}}"
```

**Load map and relocalize:**
```bash
ros2 service call /slam_toolbox/deserialize_map slam_toolbox/srv/DeserializePoseGraph \
  "{filename: '/home/user/maps/my_map', match_type: 2}"
```

**Pause mapping (localization only):**
```bash
ros2 service call /slam_toolbox/pause_new_measurements std_srvs/srv/SetBool "{data: true}"
```

**Resume mapping:**
```bash
ros2 service call /slam_toolbox/pause_new_measurements std_srvs/srv/SetBool "{data: false}"
```

### Helper Script

For convenience, a helper script is provided to simplify common operations:

```bash
# After building the package, the script will be available at:
ros2 pkg prefix llmy_slam
# Or use it directly from source:
./ros/src/llmy_slam/scripts/slam_control.sh

# Usage examples:
./scripts/slam_control.sh pause                         # Pause mapping
./scripts/slam_control.sh resume                        # Resume mapping
./scripts/slam_control.sh save /path/to/map            # Save map
./scripts/slam_control.sh save_ros /path/to/map        # Save as ROS format
./scripts/slam_control.sh load /path/to/map            # Load map
./scripts/slam_control.sh list                         # List all services
```

## Troubleshooting

### No map appearing
- Check that `/scan` topic is publishing: `ros2 topic echo /scan`
- Verify TF tree is complete: `ros2 run tf2_tools view_frames`
- Check that odometry is being published: `ros2 topic echo /omnidirectional_controller/odom`
- Verify `odom` → `base_link` TF is published: `ros2 run tf2_ros tf2_echo odom base_link`

### Poor map quality
- Adjust `minimum_travel_distance` and `minimum_travel_heading` parameters
- Increase `loop_closure` parameters for better loop detection
- Ensure your laser scan data is clean and not noisy

### Transform errors
- Verify that `odom` → `base_link` transform is being published by omnidirectional_controller:
  ```bash
  ros2 run tf2_ros tf2_echo odom base_link
  ```
- Check that all sensor frames are properly defined in the URDF
- Use `ros2 run tf2_tools view_frames` to debug TF tree
- Ensure `/omnidirectional_controller/odom` topic is publishing

## Parameters Tuning

Key parameters you might want to adjust based on your environment:

- **For small environments** (< 10m x 10m):
  - Decrease `loop_search_maximum_distance`
  - Increase `minimum_travel_distance`

- **For large environments** (> 50m x 50m):
  - Increase `loop_search_maximum_distance`
  - Decrease `minimum_travel_distance`
  - Increase `stack_size_to_use`

- **For fast-moving robots**:
  - Decrease `minimum_time_interval`
  - Increase `transform_publish_period`

## License

MIT

## References

- [slam_toolbox documentation](https://github.com/SteveMacenski/slam_toolbox)
- [slam_toolbox ROS2 tutorial](https://navigation.ros.org/tutorials/docs/using_slam_toolbox.html)

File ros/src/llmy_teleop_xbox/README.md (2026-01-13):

# llmy_teleop_xbox

Xbox controller teleoperation for LLMy robot, providing intuitive control of the omnidirectional base, 6-DOF robotic arm, and pan-tilt camera head.

## Features

- **Right stick base control** - Forward/backward and rotation
- **Button-based arm control** - All 6 joints controlled via buttons and triggers
- **Button-based arm control** - Joints 3-6 with single press and hold-to-repeat
- **D-pad camera control** - Pan (up/down) and tilt (left/right)
- **Smooth acceleration** - Gradual velocity changes for base movement
- **Deadband filtering** - Prevents controller drift
- **Joint limit enforcement** - Prevents invalid camera positions

## Control Mapping

### 🏎️ Base Movement
- **Right Stick Forward/Back** - Linear movement (forward/backward)
- **Right Stick Left/Right** - Rotation (turn left/right)
- **Left Stick Left/Right** - Lateral movement (strafe left/right)

### 🦾 Arm Control

**Joint 1 (Base Rotation):**
- **RB (Right Bumper)** - Increase joint 1 (+)
- **LB (Left Bumper)** - Decrease joint 1 (-)

**Joint 2 (Shoulder):**
- **RT (Right Trigger)** - Increase joint 2 (+)
- **LT (Left Trigger)** - Decrease joint 2 (-)

**Joint 3 (Elbow):**
- **Y Button** - Increase joint 3 (+)
- **A Button** - Decrease joint 3 (-)

**Joint 4 (Wrist 1):**
- **B Button** - Increase joint 4 (+)
- **X Button** - Decrease joint 4 (-)

**Joint 5 (Wrist 2):**
- **Start Button** - Increase joint 5 (+)
- **Back Button** - Decrease joint 5 (-)

**Joint 6 (Wrist 3):**
- **Right Stick Click** - Increase joint 6 (+)
- **Left Stick Click** - Decrease joint 6 (-)

### 📷 Camera Control

- **D-pad Left** - Tilt down (-)
- **D-pad Right** - Tilt up (+)
- **D-pad Up** - Pan right (+)
- **D-pad Down** - Pan left (-)

**Note:** All buttons support both single press (small increment) and hold-to-repeat (continuous movement).

## Configuration

### Parameters

| Parameter | Default | Description |
|---|---|---|
| `cmd_vel_topic` | `/cmd_vel_xbox` | Base velocity command topic |
| `arm_cmd_topic` | `/arm_controller/commands` | Arm command topic |
| `head_cmd_topic` | `/head_controller/commands` | Head command topic |
| `linear_scale` | `0.2` | Forward/backward speed scaling |
| `angular_scale` | `0.5` | Rotation speed scaling |
| `arm_increment` | `0.1745` (10°) | Standard joint increment |
| `arm_increment_fast` | `0.1396` (8°) | Fast joint increment (joints 1-4) |
| `stick_deadband` | `0.1` | Analog stick deadband threshold |
| `trigger_threshold` | `0.3` | Trigger press threshold |
| `arm_rate` | `30.0` | Arm/head command rate (Hz) |
| `base_rate` | `50.0` | Base command rate (Hz) |
| `acceleration_limit` | `2.0` | Max acceleration for base (m/s²) |

### Joint Limits

Camera head has enforced joint limits:
- **camera_pan**: -3.14 to 3.14 rad (full rotation)
- **camera_tilt**: -1.57 to 0.86 rad (tilt range)

## Usage

### Hardware Setup

1. Connect Xbox controller via USB or wireless adapter
2. Verify controller detection:
```bash
ls /dev/input/js*
ros2 run joy joy_enumerate_devices
```

### Launch Teleoperation

```bash
# Launch with joy node included
ros2 launch llmy_teleop_xbox teleop_xbox.launch.py

# Or launch manually
ros2 run joy joy_node &
ros2 run llmy_teleop_xbox teleop_xbox.py
```

### Custom Parameters

```bash
# Faster base movement
ros2 run llmy_teleop_xbox teleop_xbox.py --ros-args \
  -p linear_scale:=0.4 \
  -p angular_scale:=0.8

# Larger arm increments
ros2 run llmy_teleop_xbox teleop_xbox.py --ros-args \
  -p arm_increment:=0.2618  # 15 degrees
```

### Monitoring

```bash
# Monitor base commands
ros2 topic echo /cmd_vel_xbox

# Monitor arm commands
ros2 topic echo /arm_controller/commands

# Monitor head commands
ros2 topic echo /head_controller/commands

# Check joystick input
ros2 topic echo /joy
```

## Integration

This package publishes to topics that are multiplexed by the main bringup system:

- **Base commands** → `/cmd_vel_xbox` → Multiplexed to `/omnidirectional_controller/cmd_vel_unstamped`
- **Arm commands** → `/arm_controller/commands` → Processed by arm controller
- **Head commands** → `/head_controller/commands` → Processed by head controller

The `twist_mux` in `llmy_bringup` handles command prioritization, with teleop having priority 10 (medium).

## Safety Features

- **Smooth acceleration** - Base velocity changes gradually to prevent jerky motion
- **Deadband filtering** - Ignores small stick movements from drift
- **Joint limits** - Camera joints clamped to safe ranges
- **Rate limiting** - Commands published at controlled frequency
- **Zero velocity on release** - Base stops when stick returns to center

## Troubleshooting

### Controller Not Detected

```bash
# Check if controller is connected
ls /dev/input/js*

# Test joy node
ros2 run joy joy_enumerate_devices
ros2 topic echo /joy

# Check permissions
sudo chmod 666 /dev/input/js0
```

### Robot Not Responding

```bash
# Verify topics
ros2 topic list | grep -E "(cmd_vel|commands)"

# Check twist_mux status
ros2 topic echo /omnidirectional_controller/cmd_vel_unstamped

# Verify controllers are active
ros2 control list_controllers

# Enable debug logging
ros2 run llmy_teleop_xbox teleop_xbox.py --ros-args --log-level debug
```

### Arm Moving Unexpectedly

- Check stick calibration with `ros2 topic echo /joy`
- Increase `stick_deadband` parameter
- Verify arm controller is receiving commands

### Base Not Moving Smoothly

- Adjust `linear_scale` and `angular_scale`
- Check `acceleration_limit` parameter
- Verify omnidirectional controller configuration

## Dependencies

- `rclpy` - ROS2 Python client library
- `sensor_msgs` - Joy messages
- `geometry_msgs` - Twist messages
- `std_msgs` - Float64MultiArray messages
- `joy` - ROS2 joystick driver package

## Technical Details

### Command Publishing

- **Base**: Published at 50Hz with smooth acceleration limiting
- **Arm/Head**: Published at 30Hz with incremental position updates
- **Joystick**: Processed on every Joy message (typically 100Hz)

### Coordinate Frames

- Base commands use robot frame (forward = +X, left = +Y, CCW = +Z)
- Arm/head commands are joint angles in radians
- Camera pan: positive = right, negative = left
- Camera tilt: positive = up, negative = down

## License

Part of the LLMy Robot project. See main repository for license information.

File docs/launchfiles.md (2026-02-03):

# LLMy Launch Files Documentation

This document provides an overview of all launch files in the LLMy ROS 2 workspace and their parameters.

## Main System Launch Files

### llmy_bringup/launch/bringup_robot.launch.py
**Description**: Main modular launch file that coordinates all three subsystems (sensors, motion, communication).

**Parameters**:
- `use_sensors` (bool, default: `true`) - Enable all sensor systems
- `use_motion` (bool, default: `true`) - Enable motion and control systems  
- `use_communication` (bool, default: `true`) - Enable communication and web interfaces

**Includes**: sensors.launch.py, motion.launch.py, communication.launch.py

### llmy_bringup/launch/sensors.launch.py
**Description**: Sensor subsystem launch file (cameras, IMU, RPLidar).

**Parameters**:
- `use_camera` (bool, default: `true`) - Enable camera system (RealSense + wrist cam)
- `use_imu` (bool, default: `true`) - Enable IMU sensor
- `use_rplidar` (bool, default: `false`) - Enable RPLidar C1

**Includes**: camera.launch.py, imu.launch.py, rplidar_c1_launch.py

### llmy_bringup/launch/motion.launch.py
**Description**: Motion subsystem launch file (servos, ros2_control, teleop).

**Parameters**:
- `use_base_systems` (bool, default: `true`) - Enable servo manager (motor control)
- `use_control_stack` (bool, default: `true`) - Enable robot state publisher and controllers
- `use_xbox` (bool, default: `true`) - Enable Xbox controller teleoperation
- `servo_port` (string, default: `/dev/ttyTHS1`) - Serial port for servo communication
- `servo_baud` (string, default: `1000000`) - Baudrate for servo communication

**Includes**: servo_manager.launch.py, control_stack.launch.py, teleop_xbox.launch.py

### llmy_bringup/launch/communication.launch.py
**Description**: Communication subsystem launch file (rosbridge, rosboard, image compression).

**Parameters**:
- `use_rosbridge` (bool, default: `true`) - Enable rosbridge server for web interfaces
- `use_rosboard` (bool, default: `true`) - Enable rosboard web dashboard
- `use_image_compression` (bool, default: `true`) - Enable image compression and depth-to-scan

**Nodes**: rosbridge_websocket, rosboard_node, image compression nodes, depthimage_to_laserscan

## Control System Launch Files

### llmy_control/launch/base_systems.launch.py
**Description**: Launches base hardware systems including servo manager.

**Parameters**:
- `servo_port` (string, default: `/dev/ttyTHS1`) - Serial port for servo manager
- `servo_baud` (string, default: `1000000`) - Baudrate for servo manager
- `servo_config` (string, default: `''`) - Path to servo manager config file (uses package default if empty)

**Includes**: servo_manager.launch.py

### llmy_control/launch/control_stack.launch.py
**Description**: Launches the ros2_control stack with robot description and controllers.

**Parameters**: None

**Nodes**: robot_state_publisher, controller_manager, controller spawners (joint_state_broadcaster, diff_drive_controller, arm_controller, head_controller)

## Camera System Launch Files

### llmy_camera/launch/camera.launch.py
**Description**: Comprehensive camera setup with RealSense and USB wrist camera.

**Parameters**:
- `camera_name` (string, default: `head_camera`) - RealSense camera name
- `wrist_camera_device` (string, default: `/dev/video0`) - Wrist camera device path
- `enable_wrist_camera` (bool, default: `true`) - Enable wrist camera
- `device_type` (string, default: `''`) - RealSense device type (e.g., d435i, d455, l515)
- `enable_compressed` (bool, default: `false`) - Enable compressed image transport
- `enable_laser_scan` (bool, default: `false`) - Enable depth to laser scan conversion
- `laser_scan_min_height` (float, default: `-0.5`) - Minimum height for laser scan slice
- `laser_scan_max_height` (float, default: `0.5`) - Maximum height for laser scan slice
- `laser_scan_angle_min` (float, default: `-1.57`) - Minimum angle for laser scan (-90 degrees)
- `laser_scan_angle_max` (float, default: `1.57`) - Maximum angle for laser scan (+90 degrees)
- `laser_scan_angle_increment` (float, default: `0.005`) - Angular resolution of laser scan
- `laser_scan_range_min` (float, default: `0.2`) - Minimum range for laser scan
- `laser_scan_range_max` (float, default: `10.0`) - Maximum range for laser scan

**Includes**: realsense2_camera/launch/rs_launch.py

**Nodes**: wrist camera (usb_cam), RealSense camera

**Note**: Image compression and depth-to-scan are now handled by communication.launch.py

### llmy_camera/launch/realsense_only.launch.py
**Description**: Minimal RealSense camera setup.

**Parameters**:
- `camera_name` (string, default: `camera`) - RealSense camera name
- `device_type` (string, default: `d435i`) - RealSense device type

**Includes**: realsense2_camera/launch/rs_launch.py

## Sensor Launch Files

### llmy_imu/launch/imu.launch.py
**Description**: IMU sensor setup with Madgwick filter.

**Parameters**:
- `publish_rate` (float, default: `200.0`) - Publishing rate for IMU data in Hz
- `frame_id` (string, default: `imu_link`) - Frame ID for IMU data
- `use_mag` (bool, default: `true`) - Use magnetometer for orientation filtering

**Nodes**: imu_node, imu_filter_madgwick

## Teleop Launch Files

### llmy_teleop_xbox/launch/teleop_xbox.launch.py
**Description**: Xbox controller teleoperation setup.

**Parameters**:
- `joy_dev` (string, default: `0`) - Joystick device ID
- `switch_controllers` (bool, default: `true`) - Switch controllers flag

**Nodes**: joy_node, teleop_xbox (with controller command topics configured)

## Navigation & SLAM Launch Files

### llmy_nav/launch/slam_nav.launch.py
**Description**: Combined SLAM + Navigation launch — builds the map while navigating autonomously. slam_toolbox provides the map and map→odom transform, replacing both map_server and AMCL.

**Parameters**:
- `use_sim_time` (bool, default: `false`) - Use simulation time
- `autostart` (bool, default: `true`) - Automatically start lifecycle nodes

**Nodes**: slam_toolbox (async), planner_server (SmacPlanner2D), controller_server (MPPI), bt_navigator, behavior_server, velocity_smoother, lifecycle_manager_slam_nav

**Remappings**: controller output → `cmd_vel_raw`, smoother output → `cmd_vel_nav`

### llmy_nav/launch/navigation.launch.py
**Description**: Full Nav2 navigation with a pre-built map. Requires a saved map file.

**Parameters**:
- `use_sim_time` (bool, default: `false`) - Use simulation time
- `autostart` (bool, default: `true`) - Automatically start lifecycle nodes
- `map` (string) - Path to map YAML file

**Nodes**: map_server, amcl, planner_server, controller_server, bt_navigator, behavior_server, velocity_smoother, lifecycle_manager_navigation

### llmy_nav/launch/mapping.launch.py
**Description**: SLAM-only mode for building maps. No autonomous navigation — just map building while teleoperating.

**Parameters**:
- `use_sim_time` (bool, default: `false`) - Use simulation time
- `autostart` (bool, default: `true`) - Automatically start lifecycle nodes

**Nodes**: slam_toolbox (async), lifecycle_manager_slam

### llmy_nav/launch/mapfree.launch.py
**Description**: Reactive navigation without any map. Publishes an identity map→odom transform and runs local obstacle avoidance only.

**Parameters**:
- `use_sim_time` (bool, default: `false`) - Use simulation time
- `autostart` (bool, default: `true`) - Automatically start lifecycle nodes

**Nodes**: static_transform_publisher (map→odom), planner_server, controller_server, bt_navigator, behavior_server, velocity_smoother, lifecycle_manager_mapfree

### llmy_nav/launch/mode_manager.launch.py
**Description**: Orchestrates switching between navigation modes at runtime.

**Nodes**: mode_manager

## MoveIt Launch Files

### llmy_moveit/launch/moveit.launch.py
**Description**: MoveIt 2 motion planning for the 6-DOF arm. Launches move_group with OMPL planners and KDL kinematics. Expects the control stack to already be running.

**Parameters**:
- `use_sim_time` (bool, default: `false`) - Use simulation time
- `launch_rviz` (bool, default: `true`) - Launch RViz with MoveIt plugin

**Nodes**: move_group, rviz2_moveit (conditional)

**Note**: Requires `arm_trajectory_controller` to be loaded (spawned inactive by control_stack). Activate with: `ros2 control switch_controller --activate arm_trajectory_controller --deactivate arm_controller`

## Simulation Launch Files

### llmy_gazebo/launch/sim.launch.py
**Description**: Gazebo simulation environment setup.

**Parameters**:
- `gui` (bool, default: `true`) - Enable Gazebo GUI
- `pause` (bool, default: `false`) - Start simulation paused
- `spawn_z` (float, default: `0.05`) - Z position for robot spawn
- `cm_timeout` (string, default: `60`) - Controller manager timeout

**Includes**: gazebo_ros/launch/gzserver.launch.py, gazebo_ros/launch/gzclient.launch.py

**Nodes**: robot_state_publisher, spawn_entity, controller spawners (diff_drive_controller, arm_controller, head_controller - with event handlers for sequencing)

## Hardware Manager Launch Files

### llmy_servo_manager/launch/servo_manager.launch.py
**Description**: Servo motor manager for hardware communication.

**Parameters**:
- `config_file` (string, default: package config file) - Path to the servo manager config file
- `port` (string, default: `/dev/ttyUSB0`) - Serial port for motor communication
- `baud` (string, default: `2000000`) - Baud rate for serial communication

**Nodes**: servo_manager_node

### llmy_servo_manager/launch/test_brake_methods.launch.py
**Description**: Servo brake testing utility.

**Parameters**: 
- `config_file` (string, default: package config file) - Path to the servo manager config file
- `port` (string, default: `/dev/ttyUSB0`) - Serial port for motor communication  
- `baud` (string, default: `2000000`) - Baud rate for serial communication

**Nodes**: test_brake_methods

## Usage Examples

### Launch the complete robot system:
```bash
ros2 launch llmy_bringup bringup_robot.launch.py
```

### Launch with custom servo port:
```bash
ros2 launch llmy_bringup bringup_robot.launch.py servo_port:=/dev/ttyUSB1
```

### Launch desktop development environment:
```bash
ros2 launch llmy_bringup bringup_desktop.launch.py
```

### Launch simulation:
```bash
ros2 launch llmy_gazebo sim.launch.py
```

### Launch only camera system:
```bash
ros2 launch llmy_camera camera.launch.py
```

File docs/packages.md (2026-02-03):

# LLMy ROS Packages

| Package | Purpose | Language | Key Topics | Launch Command |
|---|---|---|---|---|
| **llmy_description** | Robot URDF model & transforms | XML/Python | `/robot_description`, `/tf`, `/joint_states` | `ros2 launch llmy_description view_robot.launch.py` |
| **llmy_servo_manager** | Direct motor control (C++) | C++ | `/motor_manager/*_cmd`, `/motor_manager/joint_states` | `ros2 launch llmy_servo_manager servo_manager.launch.py` |
| **llmy_servo_manager_py** | Motor control with advanced braking | Python | `/motor_manager/*_cmd`, `/motor_manager/joint_states` | `ros2 launch llmy_servo_manager_py servo_manager.launch.py` |
| **llmy_control_plugin** | ros2_control hardware bridge | C++ | `/cmd_vel`, `/arm_controller/joint_trajectory` | `ros2 launch llmy_control_plugin bringup.launch.py` |
| **llmy_teleop_xbox** | Xbox controller interface | Python | `/cmd_vel`, `/joy` | `ros2 launch llmy_teleop_xbox teleop_xbox.launch.py` |
| **llmy_control** | Controller configurations | YAML | N/A (config files) | Loaded by control_plugin |
| **llmy_camera** | RGB-D camera & vision | Python | `/head_camera/*`, `/scan`, `/wrist_camera/*` | `ros2 launch llmy_camera camera.launch.py` |
| **llmy_nav** | Navigation & SLAM modes | Python/YAML | `/cmd_vel_nav`, `/map`, `/plan` | `ros2 launch llmy_nav slam_nav.launch.py` |
| **llmy_moveit** | MoveIt 2 arm planning | YAML/Python | `/move_group/*`, `/planning_scene` | `ros2 launch llmy_moveit moveit.launch.py` |
| **llmy_mcp** | MCP bridge for LLMs | Python | `/cmd_vel_mcp`, dynamic topics | `ros2 run llmy_mcp mcp_server` |
| **llmy_imu** | IMU sensor & fusion | Python | `/imu/data`, `/imu/fused` | `ros2 launch llmy_imu imu.launch.py` |

### 📦 Detailed Package Information

#### **📐 llmy_description - Robot Model**

**What it does:** Provides the complete URDF/Xacro robot model with accurate physical properties, joint limits, collision meshes, and visual representations. This is the "digital twin" of your physical robot.

**Nodes launched:**
- `robot_state_publisher` - Publishes robot transforms and joint states
- `joint_state_publisher` - (Optional) For manual joint control in simulation

**How to run:**
```bash
# Standalone URDF visualization
ros2 launch llmy_description view_robot.launch.py

# Load robot model for other packages
ros2 run robot_state_publisher robot_state_publisher --ros-args -p robot_description:="$(xacro $(ros2 pkg prefix llmy_description)/share/llmy_description/urdf/llmy.urdf.xacro)"
```

**Key topics:**
- `/robot_description` - URDF robot model
- `/tf` and `/tf_static` - Robot transforms
- `/joint_states` - Current joint positions

#### **🔧 llmy_servo_manager - Direct Motor Control (C++)**

**What it does:** Handles low-level communication with FEETECH STS servos via serial protocol. Converts ROS2 joint commands into servo-specific position/velocity commands and provides real-time telemetry feedback.

**Nodes launched:**
- `servo_manager_node` - Main servo communication node
- `ping_test` - (Optional) Motor connectivity testing utility

**How to run:**
```bash
# Main servo manager (requires hardware)
ros2 launch llmy_servo_manager servo_manager.launch.py

# Test motor connectivity
ros2 launch llmy_servo_manager ping_test.launch.py

# Custom serial port
ros2 launch llmy_servo_manager servo_manager.launch.py port:=/dev/ttyTHS1 baud:=1000000
```

**Key topics:**
- `/motor_manager/base_cmd` - Base motor velocity commands
- `/motor_manager/arm_cmd` - Arm motor position commands  
- `/motor_manager/head_cmd` - Head motor position commands
- `/motor_manager/joint_states` - Motor telemetry feedback

**Configuration:** Edit `config/servo_manager.yaml` to adjust motor IDs, serial settings, and control parameters.

---

#### **🐍 llmy_servo_manager_py - Python Motor Control**

**What it does:** Python-based alternative to the C++ servo manager with modular architecture, advanced braking system, and improved error handling. Provides the same functionality with enhanced safety features and easier customization.

**Features:**
- **Advanced Braking System**: Three configurable braking methods to prevent power spikes
- **Modular Architecture**: Clean separation of motor management, configuration, and command handling
- **Improved Safety**: Comprehensive connectivity testing and graceful error recovery
- **Enhanced Telemetry**: Detailed motor state monitoring and diagnostics

**Nodes launched:**
- `servo_manager_node.py` - Main Python servo manager node

**How to run:**
```bash
# Main Python servo manager (requires hardware)
ros2 launch llmy_servo_manager_py servo_manager.launch.py

# Test brake methods
ros2 launch llmy_servo_manager_py test_brake_methods.launch.py

# Custom configuration
ros2 launch llmy_servo_manager_py servo_manager.launch.py config_file:=custom_config.yaml
```

**Key topics:** (Same as C++ version)
- `/motor_manager/base_cmd` - Base motor velocity commands
- `/motor_manager/arm_cmd` - Arm motor position commands  
- `/motor_manager/head_cmd` - Head motor position commands
- `/motor_manager/joint_states` - Motor telemetry feedback

**Configuration:** Edit `config/servo_manager.yaml` to adjust motor IDs, serial settings, braking method, and control parameters.

> **💡 When to use:** Choose the Python version for enhanced safety features, easier customization, or when you need advanced braking control. Both versions are fully compatible with the rest of the system.

---

#### **🔌 llmy_control_plugin - Hardware Bridge**

**What it does:** Acts as the ros2_control hardware interface, bridging standard ROS2 controllers with the servo manager. Enables seamless integration with MoveIt2, navigation, and other ROS2 tools.

**Nodes launched:**
- `controller_manager` - ros2_control manager
- `diff_drive_controller` - Base movement controller (skid-steer)
- `arm_controller` - Arm trajectory controller
- `joint_state_broadcaster` - Joint state publisher

**How to run:**
```bash
# Launch with hardware interface
ros2 launch llmy_control_plugin bringup.launch.py

# Simulation mode (requires Gazebo)
ros2 launch llmy_control_plugin bringup.launch.py use_sim_time:=true
```

**Key topics:**
- `/cmd_vel` - Base velocity commands (input)
- `/arm_controller/joint_trajectory` - Arm trajectory commands (input)
- `/joint_states` - Combined joint states (output)
- `/controller_manager/*` - Controller status and management

---

#### **🎮 llmy_teleop_xbox - Manual Control**

**What it does:** Provides intuitive Xbox controller mapping for manual robot operation. Maps controller inputs to robot movements with safety limits and smooth control.

**Nodes launched:**
- `teleop_xbox_node` - Xbox controller interface
- `joy_node` - Joystick driver

**How to run:**
```bash
# Standard Xbox controller
ros2 launch llmy_teleop_xbox teleop_xbox.launch.py

# Custom controller device
ros2 launch llmy_teleop_xbox teleop_xbox.launch.py device:=/dev/input/js1
```

**Controller mapping:**
- **Right stick:** Base movement (forward/back + rotation)
- **RB/LB:** Arm joint 1 (+/-)
- **RT/LT:** Arm joint 2 (+/-)
- **Y/A:** Arm joint 3 (+/-)
- **B/X:** Arm joint 4 (+/-)
- **Start/Back:** Arm joint 5 (+/-)
- **Stick clicks:** Arm joint 6 (+/-)
- **D-pad up/down:** Camera pan
- **D-pad left/right:** Camera tilt

**Key topics:**
- `/cmd_vel` - Base velocity output
- `/arm_controller/joint_trajectory` - Arm movement output
- `/joy` - Raw joystick data

---

#### **⚙️ llmy_control - Controller Configuration**

**What it does:** Provides controller configurations and parameter files for the skid-steer differential drive base and 6-DOF arm using standard ros2_control patterns.

**Configuration files:**
- `config/controllers.yaml` - Controller parameters
- `config/ros2_control.yaml` - Hardware interface config
- `config/joint_limits.yaml` - Safety limits

**Loaded by:** llmy_control_plugin (no standalone launch)

**Key parameters:**
- Velocity limits for base wheels
- Position/velocity limits for arm joints
- Controller gains and dynamics

#### **🗺️ llmy_nav - Navigation & SLAM**

**What it does:** Provides multiple navigation modes for the robot — full map-based navigation with AMCL, map-free reactive navigation, SLAM-only mapping, and combined SLAM + Nav2 for simultaneous mapping and navigation. Includes a mode manager for switching between modes at runtime.

**Navigation modes:**
- **mapping** — Builds a map using slam_toolbox (no autonomous navigation)
- **navigation** — Full Nav2 with a pre-built map (map_server + AMCL)
- **mapfree** — Reactive local navigation without any map
- **slam_nav** — SLAM + Nav2 combined for simultaneous mapping and autonomous navigation

**How to run:**
```bash
# SLAM + Navigation (recommended for exploration)
ros2 launch llmy_nav slam_nav.launch.py

# Map-based navigation (requires a saved map)
ros2 launch llmy_nav navigation.launch.py map:=/path/to/map.yaml

# Build a map only
ros2 launch llmy_nav mapping.launch.py

# Reactive navigation without a map
ros2 launch llmy_nav mapfree.launch.py
```

**Key topics:**
- `/cmd_vel_nav` — Navigation velocity output (via velocity_smoother)
- `/map` — Occupancy grid map
- `/plan` — Global path plan
- `/local_costmap/costmap` — Local obstacle map
- `/global_costmap/costmap` — Global planning map

**Configuration:** Config files in `config/` include controller (MPPI), planner (SmacPlanner2D), costmaps, SLAM toolbox, AMCL, behavior trees, and velocity smoother parameters.

---

#### **🦾 llmy_moveit - Arm Motion Planning**

**What it does:** Provides MoveIt 2 configuration for the SO-ARM101 6-DOF arm + gripper. Enables collision-free trajectory planning, inverse kinematics, and integration with the `arm_trajectory_controller` for precise arm manipulation.

**Nodes launched:**
- `move_group` — MoveIt 2 planning and execution server
- `rviz2_moveit` — (Optional) RViz with MoveIt plugin for interactive planning

**How to run:**
```bash
# Launch MoveIt (hardware)
ros2 launch llmy_moveit moveit.launch.py

# Launch MoveIt (simulation)
ros2 launch llmy_moveit moveit.launch.py use_sim_time:=true

# Without RViz
ros2 launch llmy_moveit moveit.launch.py launch_rviz:=false
```

**Planning groups:**
- `arm` — Joints 1-5 (chain from base to gripper), KDL kinematics, OMPL planners (RRTConnect, RRT, PRM)
- `gripper` — Joint 6

**Named poses:** `home`, `open`, `closed`

**Controller switching:** MoveIt uses `arm_trajectory_controller`. Switch from direct position control:
```bash
ros2 control switch_controller --activate arm_trajectory_controller --deactivate arm_controller
```

**Configuration:** SRDF, kinematics (KDL), joint limits, OMPL planners, and MoveIt controller mappings in `config/`.

---

#### **🤖 llmy_mcp - MCP Bridge for LLMs**

**What it does:** Dynamic Model Context Protocol (MCP) server that bridges ROS 2 to Large Language Models. Automatically discovers all ROS 2 topics and services at runtime, enabling LLMs to read sensor data, publish commands, and call services through natural language.

**Nodes launched:**
- `llmy_mcp_bridge` — ROS 2 node running inside the MCP server process

**How to run:**
```bash
# Default (stdio transport, for local MCP clients like Claude Desktop)
ros2 run llmy_mcp mcp_server

# HTTP server (SSE transport, for remote access)
ros2 run llmy_mcp mcp_server --transport sse --host 0.0.0.0 --port 8765

# With custom config
ros2 run llmy_mcp mcp_server --config config/mcp_server.yaml
```

**MCP tools exposed:**
- `list_topics` / `list_services` — Discover available ROS 2 interfaces
- `subscribe_topic` / `read_topic` — Read sensor data from any topic
- `publish_topic` / `publish_twist_stamped` — Send commands to the robot
- `call_service` — Call any ROS 2 service

**Key topics:**
- `/cmd_vel_mcp` — Default velocity command output (TwistStamped)
- Reads from any topic dynamically (auto-subscribes on demand)

**Configuration:** `config/mcp_server.yaml` controls topic/service filtering, QoS settings, auto-subscriptions, and message cache size.

---

#### **📷 llmy_camera - Vision System**

**What it does:** Integrates RGB-D cameras with compressed image transport and depth-to-laser conversion. Provides both manipulation-ready RGB-D data and navigation-ready 2D laser scans.

**Nodes launched:**
- `realsense2_camera_node` - RealSense D435 driver
- `depthimage_to_laserscan` - Depth to 2D scan converter
- `image_transport` - Compressed image streaming
- `usb_cam_node` - (Optional) Wrist camera driver

**How to run:**
```bash
# Full camera system
ros2 launch llmy_camera camera.launch.py

# RealSense only
ros2 launch llmy_camera realsense.launch.py

# With custom resolution
ros2 launch llmy_camera camera.launch.py width:=1280 height:=720
```

**Key topics:**
- `/head_camera/color/image_raw` - RGB images
- `/head_camera/depth/image_rect_raw` - Depth images
- `/head_camera/rgbd` - Combined RGB-D data
- `/scan` - 2D laser scan from depth
- `/wrist_camera/image_raw` - Wrist camera feed

---

#### **📐 llmy_imu - Orientation Sensing**

**What it does:** Handles ICM20948 9-DOF sensor integration with Madgwick sensor fusion, providing calibrated orientation data crucial for navigation and balance.

**Nodes launched:**
- `imu_filter_madgwick` - Sensor fusion node
- `icm20948_driver` - Raw IMU data driver

**How to run:**
```bash
# IMU with sensor fusion
ros2 launch llmy_imu imu.launch.py

# Raw IMU data only
ros2 run llmy_imu icm20948_driver
```

**Key topics:**
- `/imu/data` - Raw IMU measurements
- `/imu/fused` - Fused orientation estimate
- `/imu/mag` - Magnetometer data

**Calibration:** Run calibration sequence on first setup:
```bash
ros2 run llmy_imu calibrate_imu
```

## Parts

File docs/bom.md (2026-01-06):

# Bill of Materials (BOM)

This document provides a comprehensive breakdown of all components needed to build LLMy, with pricing and sourcing information for both US and EU markets.

## 🤖 Main Platform
| Part | Amount | Unit Cost (US) | Buy (US) | Unit Cost (EU) | Buy (EU) | Total(US) | Total(EU) |
|:---|:---:|:---:|:---|:---:|---:|:-:|-|
| 12V ST3215 Feetech Servo | 10 | $13.89 | [Alibaba](https://www.alibaba.com/product-detail/Feetech-STS3215-SO-ARM100-Servo-12V_1601292634404.html) | €13.38 | [Alibaba EU](https://www.alibaba.com/product-detail/Feetech-STS3215-SO-ARM100-Servo-12V_1601292634404.html) | $138.90 | €133.80 |
| WaveShare ESP32 Servo Controller | 1 | $10.55 | [Amazon](https://www.amazon.com/Expansion-Bluetooth-Control-Application-Structures/dp/B0CKT8BN73) | €4.76 | [Kamami](https://kamami.pl/en/Servo-Controllers/1187948-serial-bus-servo-driver-board-integrates-servo-power-supply-and-control-circuit-applicable-for-st-5906623428014.html) | $10.55 | €4.76 |
| Adafruit USB-PD Trigger | 2 | $5.95 | [Adafruit](https://www.adafruit.com/product/5807) | €6.90 | [Kamami](https://kamami.pl/en/wyzwalacze-usb-pd-elektonika/1188206-usb-type-c-power-delivery-dummy-breakout-module-with-usb-type-c-power-delivery-husb238-power-supply-control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) | $11.90 | €13.80 |
| Adafruit ICM20948 IMU | 1 | $14.95 | [Adafruit](https://www.adafruit.com/product/4554) | €18.91 | [Kamami](https://kamami.pl/en/sensors-6dof-9dof-10dof/587247-stemma-qt-tdk-invensense-icm-20948-9-dof-imu-module-with-9-dof-sensor-icm-20948-adafruit-4554-5906623430239.html) | $14.95 | €18.91 |
| Baseus GP12 Battery Pack (145W, 20.8Ah) | 1 | $59.99 | [Amazon](https://www.amazon.com/Baseus-20800mAh-Portable-Charger-Charging/dp/B0DQTYLGYK) | €48.99 | [Baseus EU](https://eu.baseus.com/products/energeek-gp12-power-bank-145w-20800mah) | $59.99 | €48.99 |
| SLAMTEC RPLidar C1 | 1 | $89.00 | [RobotShop](https://www.robotshop.com/products/slamtec-rplidar-c1-lidar-scanner) | €79.00 | [Kamami](https://kamami.pl/en/laser-scanner/1189121-slamtec-rplidar-c1-laser-ranging-sensor-360-omnidirectional-lidar-millimeter-level-high-definitio-5906623483501.html) | $89.00 | €79.00 |
| **Total Base Platform** | | | | | | **$325.29** | **€299.26** |

## 📷 RGB-D Cameras

**The core perception system** for LLMy uses RGB-D cameras that provide both color and depth information. This enables rich scene understanding for AI inference, manipulation, and navigation.

> 💡 **Why RGB-D?** A single sensor provides object identification with distance/size estimation. 

All software is built on the **Intel RealSense SDK** and ROS driver, but other depth cameras serve as near drop-in replacements.

| Part | Unit Cost (US) | Buy (US) | Unit Cost (EU) | Buy (EU) | Robot + Camera (US) | Robot + Camera (EU) |
|---|---:|:---|---:|:---|---:|---:|
| **YDLidar HP60C** | $202.00 | [RobotShop US](https://www.robotshop.com/products/ydlidar-hp60c-compact-lidar-sensor-02-4m-range-73-8-scan-angle) | €190.00 | [RobotShop EU](https://eu.robotshop.com/products/ydlidar-hp60c-compact-lidar-sensor-02-4m-range-73-8-scan-angle) | **$527.29** | **€489.26** |
| **Orbbec Gemini 2** | $234.00 | [Orbbec Store](https://store.orbbec.com/products/gemini-2) | €230.00 | [Orbbec EU](https://store.orbbec3d.com) | **$559.29** | **€529.26** |
| **Intel RealSense D415** | $272.00 | [RealSense Store](https://store.realsenseai.com/buy-intel-realsense-depth-camera-d415.html) | €310.00 | [Mouser EU](https://eu.mouser.com/ProductDetail/Intel/82635AWGDVKPRQ) | **$597.29** | **€609.26** |
| **Intel RealSense D435** | $314.00 | [RealSense Store](https://store.realsenseai.com/buy-intel-realsense-depth-camera-d435.html) | €317.60 | [Mouser EU](https://eu.mouser.com/ProductDetail/Intel/82635AWGDVKPRQ) | **$639.29** | **€616.86** |
| **Stereolabs ZED 2i** | $499.00 | [Stereolabs Store](https://store.stereolabs.com/products/zed-2i) | €449.00 | [Stereolabs EU](https://store.stereolabs.com/products/zed-2i) | **$824.29** | **€748.26** |

## 💻 Single Board Computers & Mini-PCs

**Recommended:** Nvidia Orin Nano Super for optimal AI performance. The battery pack delivers up to **65W per power lane** at **20V**, supporting a wide range of compute options:

| Option | Power Draw | Performance | Best For |
|---|---|---|---|
| 🥧 **Raspberry Pi 5** | ~15W | Basic | Learning, simple tasks |
| 🚀 **Nvidia Orin Nano** | ~25W | 67 TOPS of AI performace  | AI/ML inference |
| 💪 **Intel NUC** | ~30-45W | Better, Desktop Class CPU| General compute, ROS2 |
| 🔧 **Custom Mini-PC** | <65W | Variable | Specific requirements |

> 💡 **Power Note:** Any device requiring ≤65W and compatible with 20V USB-C PD will work.

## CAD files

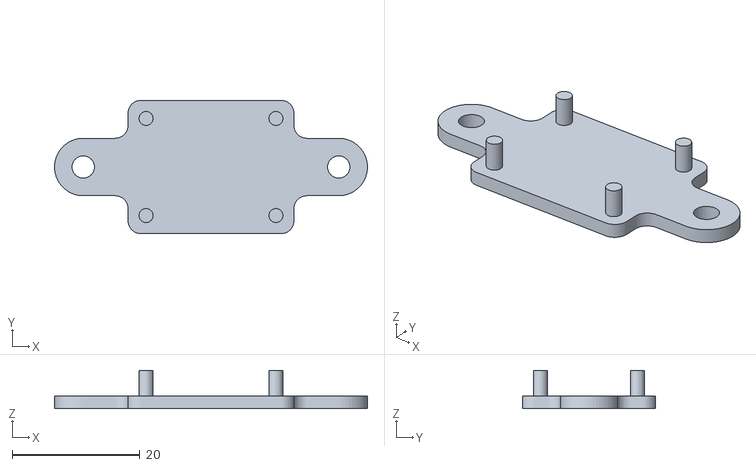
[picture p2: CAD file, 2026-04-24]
parts/base/imu_mount.stl
49.0 x 20.9 x 6.00

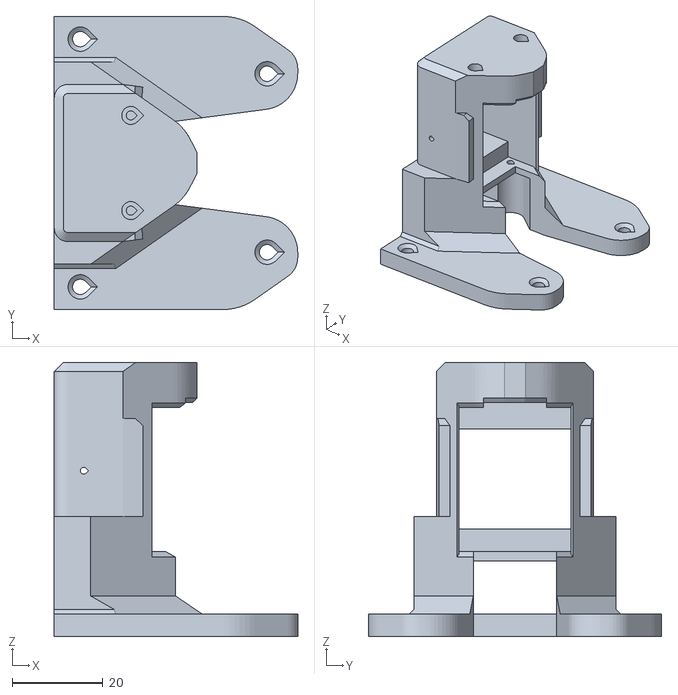
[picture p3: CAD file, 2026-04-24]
parts/camera_tower/pan_and_tilt_support.stl
53.8 x 64.7 x 60.5

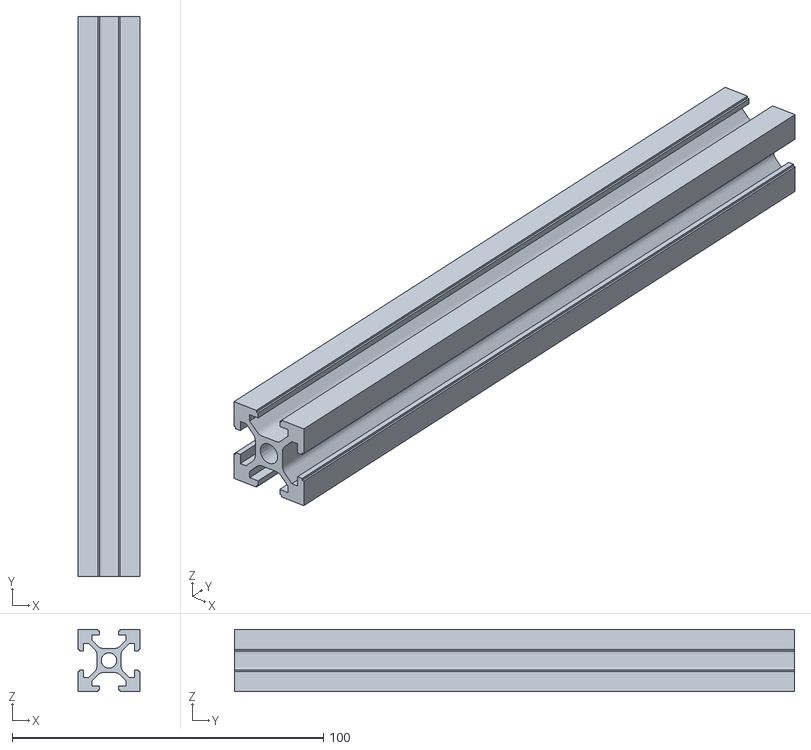
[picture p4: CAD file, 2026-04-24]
ros/src/llmy_description/meshes/horizontal_2020__2__1.stl
20.0 x 180.0 x 20.0

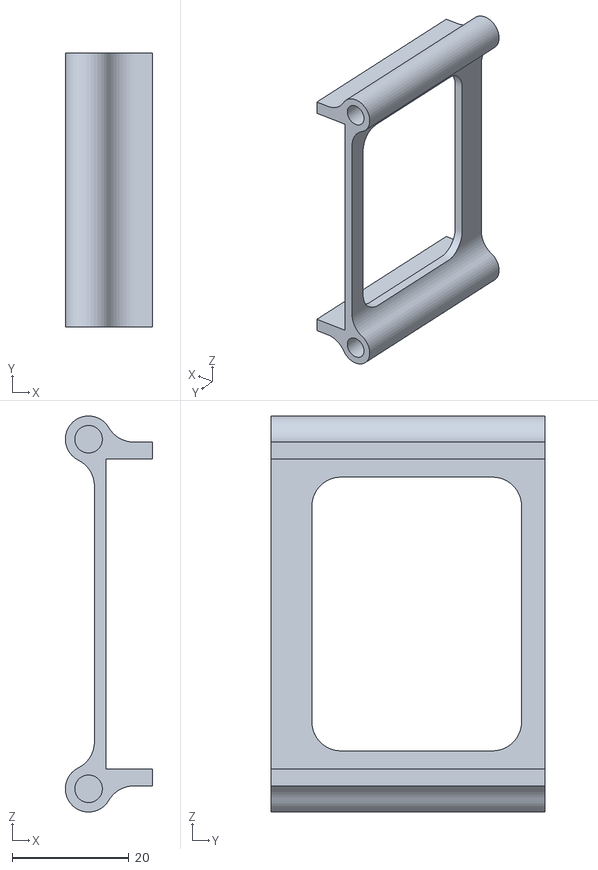
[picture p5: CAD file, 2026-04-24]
parts/base/battery_right.stl
15.0 x 47.0 x 68.0

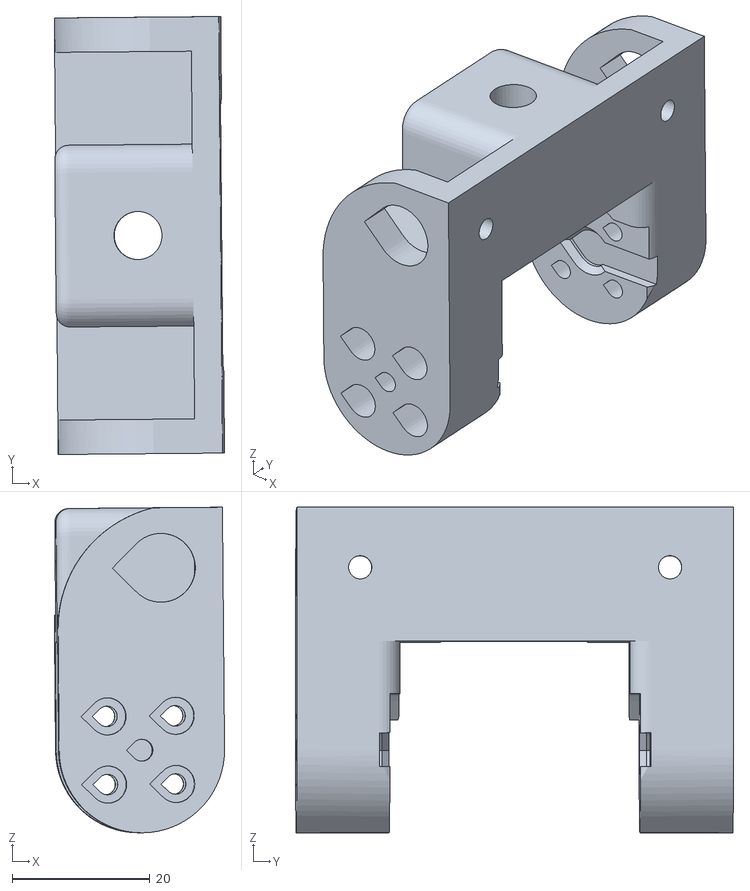
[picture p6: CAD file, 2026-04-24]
parts/camera_tower/realsense_support v1.stl
24.7 x 63.6 x 47.3

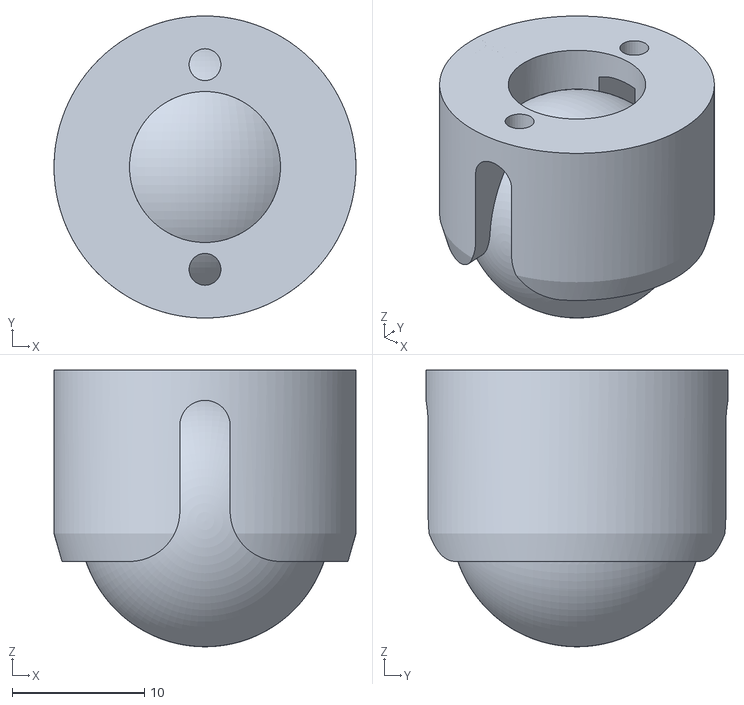
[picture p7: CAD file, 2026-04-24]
ros/src/llmy_description/meshes/right_caster_1.stl
22.9 x 22.9 x 20.9

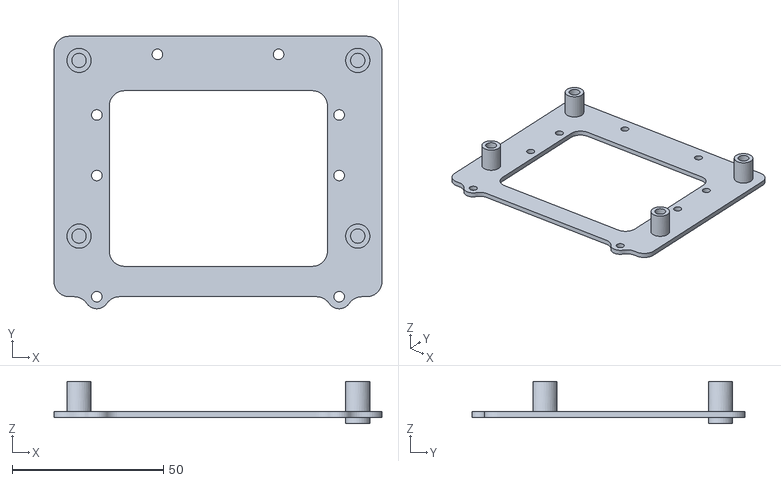
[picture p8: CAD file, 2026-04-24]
parts/base/orin_mount.stl
108.3 x 90.0 x 14.0

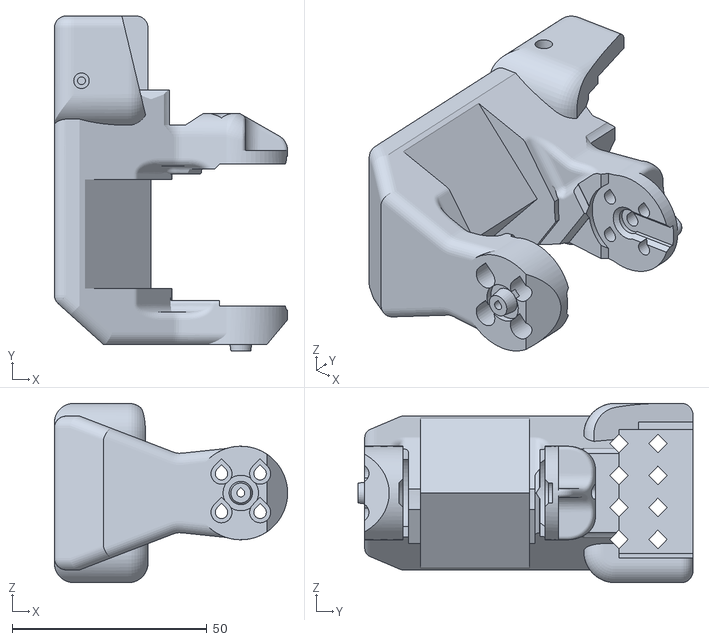
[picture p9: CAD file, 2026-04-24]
parts/camera_tower/pan_link.stl
59.8 x 85.9 x 46.0

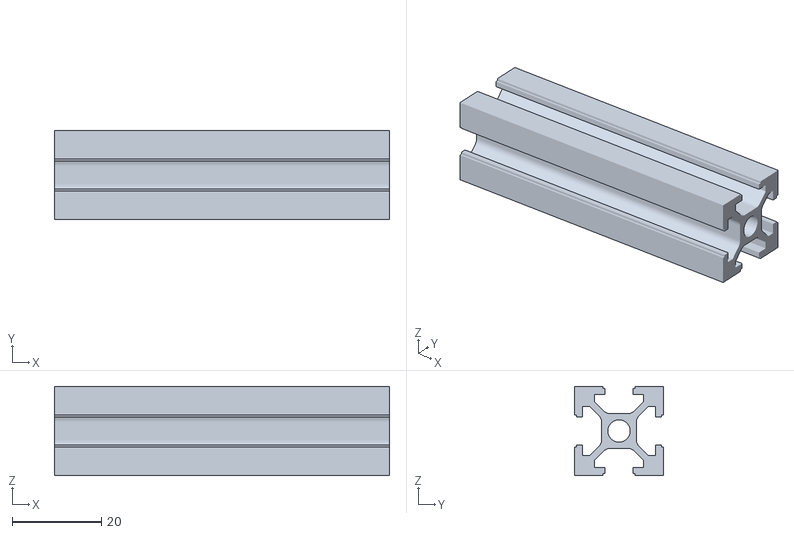
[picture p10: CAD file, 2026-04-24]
ros/src/llmy_description/meshes/horizontal_2020__1___1__1.stl
75.0 x 20.0 x 20.0

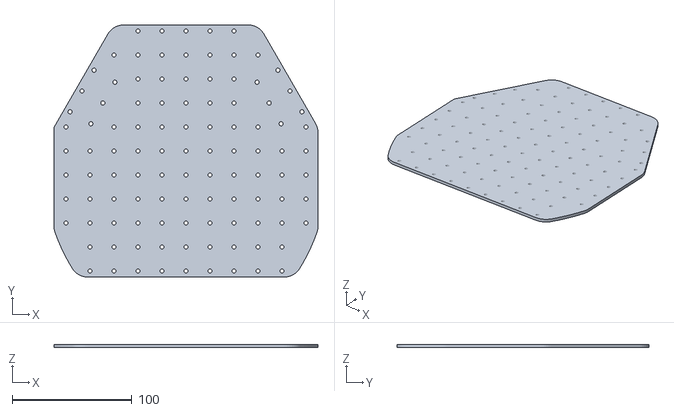
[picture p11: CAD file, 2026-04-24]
parts/base/base_plate.stl
220.0 x 210.0 x 2.83

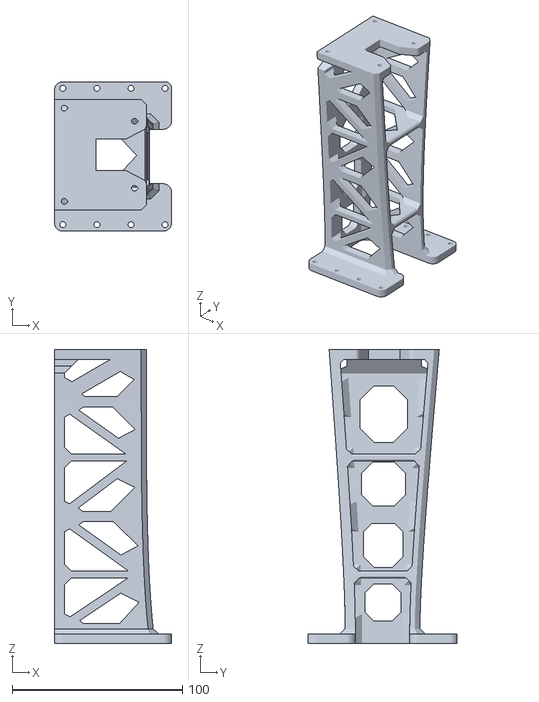
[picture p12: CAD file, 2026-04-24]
parts/camera_tower/tower.stl
68.9 x 87.7 x 172.6

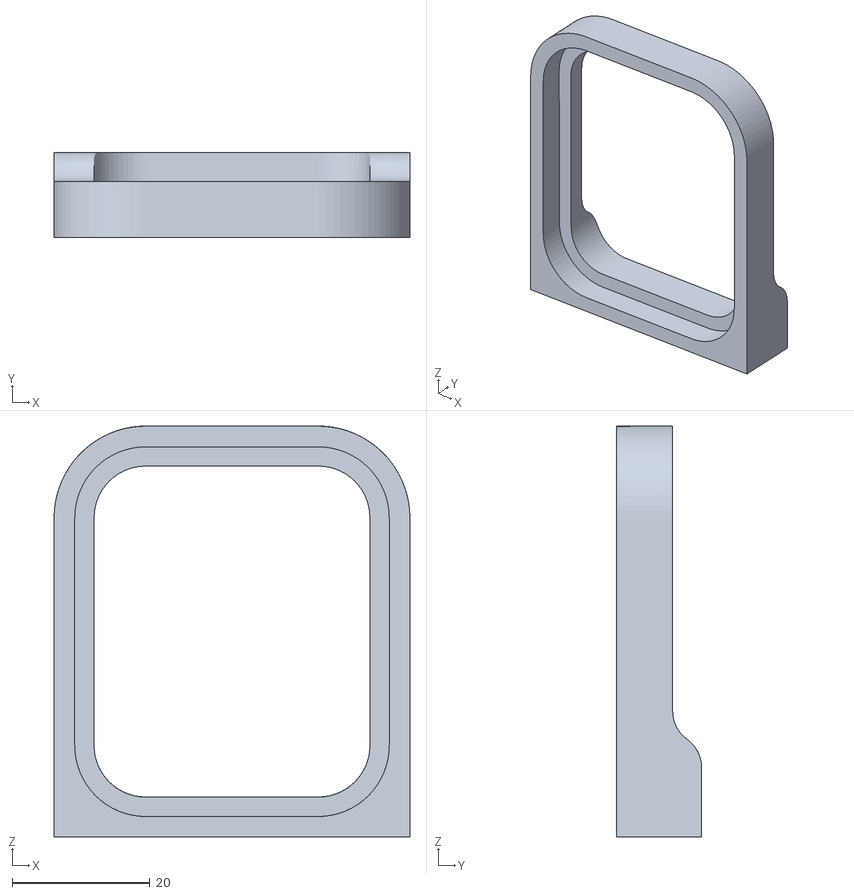
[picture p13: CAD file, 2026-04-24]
ros/src/llmy_description/meshes/right_battery_mount_1.stl
51.6 x 12.4 x 59.6

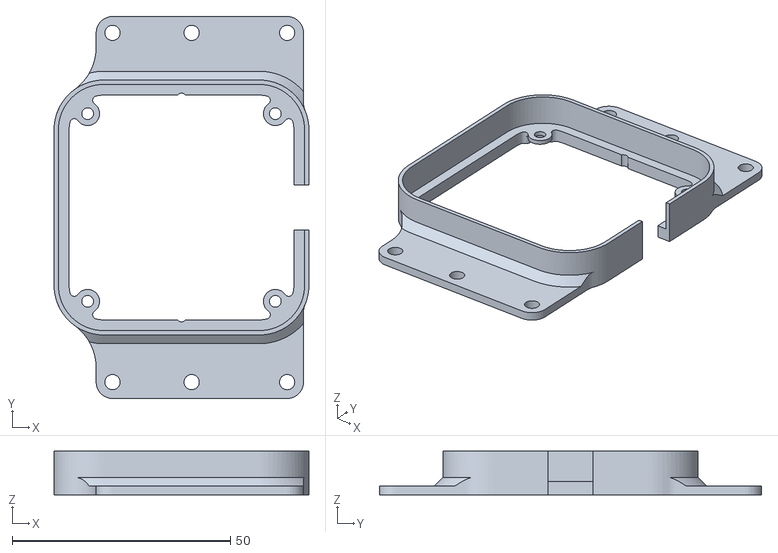
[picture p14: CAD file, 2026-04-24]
parts/base/lidar_mount.stl
58.4 x 87.5 x 10.0

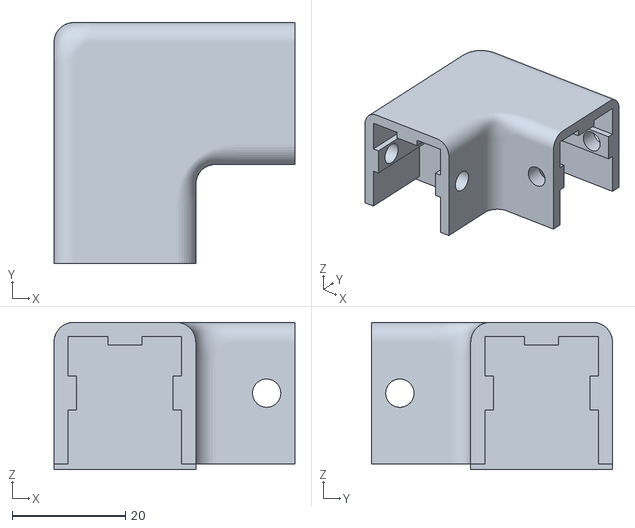
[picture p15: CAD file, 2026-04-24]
ros/src/llmy_description/meshes/Extrusion_3_way__joint_v1__2___2___1__1.stl
42.5 x 42.5 x 26.0

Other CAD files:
parts/base/battery_left.stl
ros/src/llmy_description/meshes/modular_floor__1__1.stl
parts/base/second_plate.stl
ros/src/llmy_description/meshes/Moving_Jaw_08d_v1_1.stl
parts/base/third_plate.stl
ros/src/legacy/llmy_description.bak/meshes/arm_base_1.stl
ros/src/legacy/llmy_description.bak/meshes/arm_base_rotation_link_1.stl
ros/src/legacy/llmy_description.bak/meshes/arm_base_rotation_link_cover_1.stl
ros/src/legacy/llmy_description.bak/meshes/arm_base_rotation_servo_1.stl
ros/src/legacy/llmy_description.bak/meshes/arm_elbow_link_1.stl
ros/src/legacy/llmy_description.bak/meshes/arm_elbow_servo_1.stl
ros/src/legacy/llmy_description.bak/meshes/arm_gripper_1.stl
ros/src/legacy/llmy_description.bak/meshes/arm_gripper_servo_1.stl
ros/src/legacy/llmy_description.bak/meshes/arm_jaw_1.stl
ros/src/legacy/llmy_description.bak/meshes/arm_shoulder_link_1.stl
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

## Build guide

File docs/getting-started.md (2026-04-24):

# Getting Started with LLMy

This guide walks you through setting up LLMy from your first simulation to running on real hardware.

## Prerequisites

### System Requirements
- **OS:** Ubuntu 22.04 LTS
- **ROS2:** Humble Hawksbill
- **Simulator:** Gazebo Classic (for simulation)

### Hardware Requirements (Real Robot Only)
- FEETECH STS3215 servos (12x)
- Serial motor controller (FE-URT-1 or Waveshare adapter)
- USB-C power bank (145W with PD trigger)
- Single-board computer (Raspberry Pi 5 or Jetson Orin Nano)

### Optional Peripherals
- Xbox controller (for teleoperation)
- RealSense D435i / ZED 2i / Orbbec Gemini 2 (RGB-D camera)
- ICM-20948 IMU
- RPLidar C1 (LIDAR)

---

## Installation

### 1. Install ROS2 Humble

If you don't have ROS2 Humble installed:

```bash
sudo apt update && sudo apt install -y software-properties-common
sudo add-apt-repository universe
sudo apt update && sudo apt install -y curl
sudo curl -sSL https://raw.githubusercontent.com/ros/rosdistro/master/ros.key -o /usr/share/keyrings/ros-archive-keyring.gpg
echo "deb [arch=$(dpkg --print-architecture) signed-by=/usr/share/keyrings/ros-archive-keyring.gpg] http://packages.ros.org/ros2/ubuntu $(. /etc/os-release && echo $UBUNTU_CODENAME) main" | sudo tee /etc/apt/sources.list.d/ros2.list > /dev/null
sudo apt update
sudo apt install -y ros-humble-desktop
```

### 2. Clone LLMy

```bash
git clone https://github.com/cristidragomir97/llmy.git llmy_ws
cd llmy_ws/ros
```

### 3. Install Dependencies

```bash
# Install vcstool for managing repository dependencies
sudo apt install -y python3-vcstool

# Import external ROS2 packages (diff drive controllers, rplidar)
vcs import src < repos.vcs

# Install all workspace dependencies
rosdep install --from-paths src --ignore-src -r -y

# Optional: Install additional hardware support packages
sudo apt install -y \
    ros-humble-realsense2-camera \
    ros-humble-compressed-image-transport \
    ros-humble-depthimage-to-laserscan \
    ros-humble-imu-filter-madgwick
```

### 4. Build the Workspace

```bash
colcon build --symlink-install
source install/setup.bash
```

**Tip:** Add `source ~/llmy_ws/ros/install/setup.bash` to your `~/.bashrc` to automatically source the workspace.

---

## Simulation Quickstart

The fastest way to see LLMy in action is through Gazebo simulation.

### Launch the Simulation

```bash
# Terminal 1: Start Gazebo with the robot
ros2 launch llmy_gazebo sim.launch.py
```

You should see the robot spawn in Gazebo with all controllers loaded.

### Control with Xbox Controller (Optional)

```bash
# Terminal 2: Launch Xbox teleop
ros2 launch llmy_teleop_xbox teleop_xbox.launch.py
```

**Controller Mapping:**
- **Right Stick:** Drive base (forward/back + rotation)
- **RB/LB Buttons:** Arm joint 1 (+/-)
- **RT/LT Triggers:** Arm joint 2 (+/-)
- **Y/A Buttons:** Arm joint 3 (+/-)
- **B/X Buttons:** Arm joint 4 (+/-)
- **Start/Back Buttons:** Arm joint 5 (+/-)
- **Stick Clicks:** Arm joint 6 (+/-)
- **D-Pad Up/Down:** Camera pan
- **D-Pad Left/Right:** Camera tilt

### Verify Controllers are Running

```bash
# List active controllers
ros2 control list_controllers

# Expected output:
# arm_controller[joint_trajectory_controller/JointTrajectoryController] active
# diff_drive_controller[diff_drive_controller/DiffDriveController] active
# head_controller[joint_trajectory_controller/JointTrajectoryController] active
```

---

## Hardware Setup

### Step 1: Configure Servo IDs

Before assembly, configure all servo IDs and mark them physically.

```bash
cd ~/llmy_ws/scripts

# Interactive mode - connect servos one at a time
python3 set_servo_id.py
```

**ID Assignment:**
- Base (drivetrain): **1, 2, 3, 4**
- Arm joints: **5, 6, 7, 8, 9, 10**
- Head (pan/tilt): **11, 12**

**Mark each servo** with a pen/marker after setting its ID to avoid confusion during assembly.

**Verify all servos:**
```bash
python3 set_servo_id.py --list
```

See [`scripts/README.md`](../scripts/README.md) for detailed instructions.

### Step 2: Build Software & Test Before Assembly

Build the ROS workspace and verify servo communication before physical assembly.

```bash
cd ~/llmy_ws/ros
colcon build --symlink-install
source install/setup.bash
```

**Test servo connectivity:**
```bash
# Connect all servos via daisy-chain temporarily
ros2 launch llmy_servo_manager ping_test.launch.py
```

This ensures all electronics work before you commit to full assembly.

### Step 3: Physical Assembly

**Required Tools:**
- Soldering iron (for heat-set inserts)
- M3 screws and hex wrenches
- Marker/pen (for labeling)

**Assembly Sequence:**

#### Step 1: Prepare Structural Parts
Insert M3 heat-set nuts using a soldering iron into:
- [servo_mount.stl](../parts/base/servo_mount.stl) (base wheel mounts)
- [battery_left.stl](../parts/base/battery_left.stl) (battery holder left side)
- [battery_right.stl](../parts/base/battery_right.stl) (battery holder right side)

#### Step 2: Drivetrain Assembly
- Install [wheel_hub.stl](../parts/base/wheel_hub.stl) on drivetrain servos **(IDs 1, 2, 3, 4)**
- Attach standard wheels to hubs
- Mount servos into [servo_mount.stl](../parts/base/servo_mount.stl)

#### Step 3: Base Platform
- Mount the four drivetrain assemblies to the base plate:
  - **Servo ID 1** → Front-left position
  - **Servo ID 2** → Back-left position
  - **Servo ID 3** → Front-right position
  - **Servo ID 4** → Back-right position
- Install battery mounts ([battery_left.stl](../parts/base/battery_left.stl), [battery_right.stl](../parts/base/battery_right.stl))
- If using LiDAR: mount to [lidar_mount.stl](../parts/base/lidar_mount.stl)
- Slide USB-C power bank into battery holder slot

#### Step 4: Arm Assembly
Assemble the 6-DOF arm following the [official SO-ARM100 instructions](https://www.hiwonder.com/products/so-arm100).
- Use servos **IDs 5-10** in order from base to gripper
- Ensure servo horns are centered before assembly

#### Step 5: Second Floor Integration
Mount on the second floor platform:
- Assembled robot arm
- Single-board computer (Raspberry Pi 5 or Jetson Orin Nano) with [orin_mount.stl](../parts/base/orin_mount.stl)
- USB-PD trigger modules (2x for 12V power) with [adafruit_usb_pd_mount.stl](../parts/base/adafruit_usb_pd_mount.stl)
- IMU sensor (ICM-20948) with [adafruit_icm_mount.stl](../parts/base/adafruit_icm_mount.stl)
- I2C switch module with [adafruit_i2c_switch_mount.stl](../parts/base/adafruit_i2c_switch_mount.stl)
- Motor controller with [fe_urt_1_mount.stl](../parts/base/fe_urt_1_mount.stl)

#### Step 6: Wiring - First Pass
- Route servo wires through cable management holes
- Create daisy-chain starting from **base servo 1** → continuing through all servos → ending at **camera tilt servo (ID 12)**
- Leave one free connector at the start (will connect to motor controller)
- Verify you have a clean daisy-chain from base to camera

#### Step 7: Camera Tower
- Assemble pan-tilt mechanism using head servos **(IDs 11, 12)**
- Mount to camera tower structure
- Attach RGB-D camera (RealSense/ZED/Orbbec)
- Install tower on top floor platform

#### Step 8: Motor Controller Placement
- Mount FE-URT-1 or Waveshare servo controller to the back of the arm base using [fe_urt_1_mount.stl](../parts/base/fe_urt_1_mount.stl) or [WaveShare_Mounting_Plate_SO101.stl](https://github.com/TheRobotStudio/SO-ARM100/blob/main/STL/SO101/Individual/WaveShare_Mounting_Plate_SO101.stl)
- Connect daisy-chain free connector to controller output
- Connect controller to SBC via USB or UART

#### Step 9: Complete Wiring
- **Power:**
  - USB-PD module 1 → SBC (12V or 5V depending on trigger)
  - USB-PD module 2 → Motor controller (12V)
- **Data:**
  - Camera → SBC (USB)
  - IMU → SBC (I2C)
  - Motor controller → SBC (USB or UART)
  - LiDAR → SBC (USB, if installed)
- **Organize cables** with zip ties and ensure nothing interferes with moving parts

**Assembly Tips:**
- Double-check servo IDs before installation
- Test each servo individually before daisy-chaining
- Leave slack in wiring for joint movement
- Use cable management holes to prevent wire snagging
- Take photos during assembly for reference

### Step 4: Calibrate the Arm

After assembly, calibrate the arm's zero position and joint limits.

**⚠️ Important:** Stop any running ROS nodes first:
```bash
pkill -f servo_manager
```

**Run calibration wizard:**
```bash
cd ~/llmy_ws/scripts
python3 calibrate_arm.py --config ~/llmy_ws/ros/src/llmy_servo_manager/config/servo_manager.yaml
```

**Calibration process:**
1. Position arm fully erect (vertical) with gripper closed → set zero position
2. For each joint, move to minimum position → record limit
3. For each joint, move to maximum position → record limit
4. Script saves calibration data to config file

This ensures safe operation by preventing the arm from exceeding physical limits.

See [`scripts/README.md`](../scripts/README.md) for detailed calibration instructions.

### Step 5: Launch the Robot

Configure serial port access:

```bash
# Give user permission for serial port
sudo usermod -a -G dialout $USER
# Log out and back in for changes to take effect

# Identify your servo controller port
ls /dev/ttyUSB* /dev/ttyACM* /dev/ttyTHS*
```

**Common ports:**
- `/dev/ttyUSB0` - USB adapter
- `/dev/ttyACM0` - USB CDC adapter
- `/dev/ttyTHS1` - Jetson hardware UART

Update port in config if needed:
```bash
nano ~/llmy_ws/ros/src/llmy_servo_manager/config/servo_manager.yaml
# Change: port: "/dev/ttyTHS1" to your port
```

**Launch the complete robot system:**

**Single-command bringup (recommended):**

```bash
ros2 launch llmy_bringup bringup_robot.launch.py
```

**With custom serial configuration:**

```bash
ros2 launch llmy_bringup bringup_robot.launch.py \
    servo_port:=/dev/ttyUSB0 \
    servo_baud:=1000000
```

**Disable specific subsystems:**

```bash
ros2 launch llmy_bringup bringup_robot.launch.py \
    use_camera:=false \
    use_xbox:=false
```

### Launch Components Individually (Advanced)

For debugging or custom configurations, launch subsystems separately:

```bash
# Terminal 1: Servo manager (low-level motor control)
ros2 launch llmy_control base_systems.launch.py

# Terminal 2: Hardware interface & controllers
ros2 launch llmy_control_plugin bringup.launch.py

# Terminal 3: Camera system (optional)
ros2 launch llmy_camera camera.launch.py

# Terminal 4: IMU sensor (optional)
ros2 launch llmy_imu imu.launch.py

# Terminal 5: Xbox controller (optional)
ros2 launch llmy_teleop_xbox teleop_xbox.launch.py
```

---

## Verification & Testing

### Check System Status

```bash
# Verify all controllers are active
ros2 control list_controllers

# List active ROS2 topics
ros2 topic list

# Monitor system diagnostics
ros2 topic echo /diagnostics
```

### Test Motor Communication

```bash
# Check joint states from motor manager
ros2 topic echo /motor_manager/joint_states --once

# Run servo connectivity test
ros2 launch llmy_servo_manager ping_test.launch.py
```

### Verify Sensor Data

```bash
# Camera stream (if enabled)
ros2 topic echo /camera/color/image_raw --once

# IMU data (if enabled)
ros2 topic echo /imu/fused --once

# LIDAR scan (if enabled)
ros2 topic echo /scan --once
```

### Test Manual Control

With Xbox controller connected and teleop running:
1. Gently move the right stick → base should move
2. Move the left stick → arm joints 1 & 2 should respond
3. Press D-pad → camera should pan/tilt

---

## Troubleshooting

### Controllers Not Loading

**Symptom:** `ros2 control list_controllers` shows controllers as `unconfigured` or `inactive`

**Solutions:**
```bash
# Check hardware interface connection
ros2 topic echo /motor_manager/joint_states --once

# Manually load controllers
ros2 control load_controller arm_controller
ros2 control configure_controller arm_controller
ros2 control switch_controllers --activate arm_controller
```

### Servo Communication Errors

**Symptom:** Timeout errors or `Failed to communicate with servo ID X`

**Solutions:**
1. Verify servo IDs match configuration file
2. Check baud rate: `servo_baud:=1000000` (common values: 115200, 1000000)
3. Test individual servos with ping test
4. Check physical connections and power supply

### Camera Not Detected

**Symptom:** No camera topics appearing

**Solutions:**
```bash
# List USB devices
lsusb

# Test RealSense directly
realsense-viewer

# Check launch parameters
ros2 launch llmy_camera camera.launch.py --show-args
```

### Xbox Controller Not Responding

**Symptom:** Robot doesn't move with controller input

**Solutions:**
```bash
# Verify controller is detected
ls /dev/input/js*

# Test controller input
jstest /dev/input/js0

# Check teleop node is publishing
ros2 topic echo /cmd_vel
```

---

## Next Steps

### For Developers

- **Explore Packages:** Read the [detailed package documentation](packages.md)
- **Understand Architecture:** Review the system architecture in the [main README](../README.md#-architecture)
- **Customize Configuration:** Edit YAML files in `ros/src/*/config/`
- **Build Custom Modules:** Create new ROS2 packages in `ros/src/`

### Community & Support

- **Issues:** Report bugs at [github.com/cristidragomir97/llmy/issues](https://github.com/cristidragomir97/llmy/issues)
- **Discussions:** Join conversations in GitHub Discussions
- **Documentation:** Contribute improvements via pull requests
---

**You're ready to start experimenting with LLMy!**

For hardware assembly details, see [Assembly Guide](assembly.md). For BOM and sourcing, check [BOM Documentation](bom.md).

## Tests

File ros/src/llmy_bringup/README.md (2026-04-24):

# llmy_bringup

The LLMy Bringup package provides modular launch files that coordinate all LLMy subsystems to bring up the complete robot. The system is organized into three main subsystems for flexible deployment and debugging.

## Modular Architecture

The bringup system is organized into three main categories:

### 1. **Sensors** (`sensors.launch.py`)
- **Cameras**: RealSense RGB-D head camera and USB wrist camera
- **IMU**: Orientation and motion sensing
- **RPLidar**: 2D laser scanner (optional)

### 2. **Motion** (`motion.launch.py`) 
- **Servo Manager**: Low-level motor control via serial communication
- **ROS2 Control Stack**: Robot state publisher, controller manager, and spawners
- **Teleop**: Xbox controller interface
- **Command Velocity Multiplexing**: twist_mux for multiple control sources

### 3. **Communication** (`communication.launch.py`)
- **Rosbridge Server**: WebSocket interface for web applications
- **Rosboard**: Web-based dashboard for monitoring and visualization
- **Image Compression**: Bandwidth optimization for camera feeds
- **Depth-to-Scan**: Convert depth images to laser scan format

## Launch Files

### `bringup_robot.launch.py` (Main Launcher)

Coordinates all three subsystems with high-level enable/disable flags.

| Argument | Default | Description |
|---|---|---|
| `use_sensors` | `true` | Enable all sensor systems |
| `use_motion` | `true` | Enable motion and control systems |
| `use_communication` | `true` | Enable communication and web interfaces |

### `sensors.launch.py`

| Argument | Default | Description |
|---|---|---|
| `use_camera` | `true` | Enable camera system (RealSense + wrist cam) |
| `use_imu` | `true` | Enable IMU sensor |
| `use_rplidar` | `false` | Enable RPLidar C1 |

### `motion.launch.py`

| Argument | Default | Description |
|---|---|---|
| `use_base_systems` | `true` | Enable servo manager (motor control) |
| `use_control_stack` | `true` | Enable robot state publisher and controllers |
| `use_xbox` | `true` | Enable Xbox controller teleoperation |
| `servo_port` | `/dev/ttyTHS1` | Serial port for servo communication |
| `servo_baud` | `1000000` | Baudrate for servo communication |

### `communication.launch.py`

| Argument | Default | Description |
|---|---|---|
| `use_rosbridge` | `true` | Enable rosbridge server for web interfaces |
| `use_rosboard` | `true` | Enable rosboard web dashboard |
| `use_image_compression` | `true` | Enable image compression and depth-to-scan |

## Usage Examples

### Full System Startup

```bash
# Launch complete robot with all systems
ros2 launch llmy_bringup bringup_robot.launch.py
```

### Modular System Startup

```bash
# Launch only sensors (cameras, IMU, optional LiDAR)
ros2 launch llmy_bringup sensors.launch.py

# Launch only motion systems (servos, control, teleop)
ros2 launch llmy_control motion.launch.py

# Launch only communication (web interfaces, compression)
ros2 launch llmy_bringup communication.launch.py
```

### Custom Configurations

```bash
# Launch without communication systems
ros2 launch llmy_bringup bringup_robot.launch.py use_communication:=false

# Launch with RPLidar enabled
ros2 launch llmy_bringup sensors.launch.py use_rplidar:=true

# Launch motion without Xbox controller
ros2 launch llmy_control motion.launch.py use_xbox:=false

# Launch sensors without cameras (IMU only)
ros2 launch llmy_bringup sensors.launch.py use_camera:=false

# Launch with custom serial port
ros2 launch llmy_control motion.launch.py servo_port:=/dev/ttyUSB0
```

### Development Scenarios

```bash
# Sensors + Communication (no motion for safety)
ros2 launch llmy_bringup bringup_robot.launch.py use_motion:=false

# Motion only (for control testing)
ros2 launch llmy_control motion.launch.py

# Full sensor suite with LiDAR
ros2 launch llmy_bringup sensors.launch.py use_rplidar:=true

# Communication with image compression disabled
ros2 launch llmy_bringup communication.launch.py use_image_compression:=false
```

## Command Velocity Multiplexing

The motion launch file includes a `twist_mux` node that multiplexes command velocity from multiple sources:

| Source | Topic | Priority | Description |
|---|---|---|---|
| Xbox | `/cmd_vel_xbox` | 15 (highest) | Xbox controller input |
| Teleop | `/cmd_vel_teleop` | 10 | Manual teleoperation interface |
| Nav | `/cmd_vel_nav` | 5 (lowest) | Navigation stack commands |

All sources are multiplexed to `/omnidirectional_controller/cmd_vel_unstamped` with a 0.5 second timeout.

## Web Interfaces

### Rosboard Dashboard
Access the web dashboard at: `http://localhost:8888`

Features:
- Topic visualization and monitoring
- TF tree viewer
- Live camera feeds
- Service/action inspection
- Parameter configuration

### Rosbridge WebSocket
WebSocket server available at: `ws://localhost:9090`

Enables:
- Web application integration
- Remote monitoring and control
- Real-time data streaming

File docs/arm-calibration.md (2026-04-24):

# Arm Calibration

This guide explains how to align the physical arm's encoder zero with the URDF's zero configuration, so the robot's internal model matches reality.

## Why this matters

The whole software stack (`st3215_manager`, `llmy_control_plugin`) hardcodes a single assumption:

> **Servo tick `2048` corresponds to `0 rad` in the URDF.**

See `st3215_manager/st3215_manager/command_handler.py:77-78` and `telemetry.py:101` — there is no per-joint offset parameter anywhere. Whatever mechanical pose the servo reports as tick 2048 **is** the URDF zero, by definition.

If the arm was assembled such that (for example) joint 2's "straight down" reads as tick 1500, then:
- `rviz` renders the joint bent ~48° when the real arm is actually straight.
- MoveIt plans in URDF frame and commands motion the real arm can't execute without self-collision.
- `command_handler.py:79` silently clamps to `[0, 4095]`, so out-of-range commands produce truncated motion instead of errors.

The fix is to burn the current physical pose as the servo's new center into EEPROM, so `ReadPosition` returns ~2048 when the arm is in the URDF-zero configuration.

## What won't break

Turning the nodes on with an uncalibrated arm does **not** cause runaway motion. Three guardrails prevent jumps at startup:

1. `motor_manager.py:102-114` reads the current tick and immediately sends `MoveTo(current_pos)` — the arm holds wherever it is.
2. `ros2_control_bridge.cpp:186-200` forces `cmd_pos_ = pos_state_` until meaningful joint states arrive — any controller command is overridden with "hold current position" during the handshake.
3. `command_handler.py:79` clamps ticks to the servo's electrical range.

The danger shows up only when something **plans** from the reported state (MoveIt, scripted trajectories, teleop). That's why calibration matters before using the arm, not before boot.

## Prerequisites

- All ROS nodes using the servo bus must be stopped (`st3215_manager`, `llmy_bringup`, etc.) — the calibration script and the manager node can't share `/dev/ttyTHS1`.
- Arm assembled and powered, but unrestrained enough that you can move each joint by hand.
- You know what URDF zero looks like for this arm. If unsure, launch `llmy_description` in rviz with all joint states at `0.0` and use that visual as your reference pose.

## Procedure

### 1. Verify the motor IDs

Open `scripts/calibrate_arm.py` and confirm the IDs match `ros/src/st3215_manager/config/llmy.yaml`:

```yaml
# config/llmy.yaml
arm:
  motor_ids: [3, 4, 5, 6, 7, 8]
```

Edit `calibrate_arm.py:36` if needed:

```python
'arm_ids': [3, 4, 5, 6, 7, 8],
```

The script ships with `[4, 5, 6, 7, 8, 9]` as a default; running with the wrong IDs will skip motor 3 and fail to talk to a nonexistent motor 9.

### 2. Shut down the servo bus

```bash
# Stop the bringup or any node opening /dev/ttyTHS1
# e.g. Ctrl-C the terminal running `ros2 launch llmy_bringup bringup_robot.launch.py`
```

### 3. Pose the arm

The script disables torque (`StopServo`) so you can move each joint freely. Pose the arm to match URDF zero — typically all links aligned with their parent frame's origin (straightened / neutral). Check against rviz if needed.

### 4. Run the live calibration

```bash
python3 scripts/calibrate_arm.py --live --port /dev/ttyTHS1
```

The live mode continuously prints each joint's current tick, radian, and degree value. When all readings look right (the arm is still in the intended pose), press **Enter**.

For each servo the script runs:

1. `UnLockEprom(id)` — make EEPROM writable.
2. `DefineMiddle(id)` — write current position as the new tick-2048 center.
3. `LockEprom(id)` — commit and protect.

Press `q` to exit when done.

### 5. Power-cycle the servos

Feetech EEPROM writes don't always take effect until the servo reboots. Power the bus off and on.

### 6. Verify

Bring the arm back up and spot-check:

```bash
ros2 launch llmy_bringup bringup_robot.launch.py
ros2 topic echo /joint_states
```

With the arm physically in the URDF-zero pose, every arm joint's `position` should be near `0.0` rad (within a few mrad is fine). `rviz` rendering the `robot_description` should now match reality.

## After calibration

Once hardware zero matches URDF zero, tighten the URDF joint limits in `llmy_description/urdf/LLMy.xacro` (`<limit lower=... upper=...>`) to match the real mechanical range. Use the full calibration flow (`python3 scripts/calibrate_arm.py` without `--live`) to capture min/max ticks for each joint — the wizard prompts through each joint individually and logs the range in degrees. Translate those into radian limits in the URDF so planners reject unreachable goals up front instead of hitting the driver clamp.

## Troubleshooting

- **`DefineMiddle` appears to succeed but ticks don't change.** The lock byte (register 55) wasn't cleared. The script handles this via `UnLockEprom`; if you're calling the library directly, unlock first.
- **Joint reads near 0 ticks or near 4095 after calibration.** The servo was already near its electrical end-stop when you pressed Enter. Back it off toward the middle of its mechanical range, re-pose, and recalibrate.
- **`received_meaningful_joint_states_` never flips true, arm ignores commands.** See `ros2_control_bridge.cpp:158-161` — the gate requires `|pos| > 0.005 rad` on at least one arm/camera joint. If every joint calibrates to *exactly* zero, nudge one joint a fraction of a degree before bringing up ros2_control, or relax the threshold.

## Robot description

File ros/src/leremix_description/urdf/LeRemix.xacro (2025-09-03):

<?xml version="1.0" ?>
<robot name="LeRemix" xmlns:xacro="http://www.ros.org/wiki/xacro">

<xacro:include filename="$(find leremix_description)/urdf/materials.xacro" />


<link name="base_link">
  <inertial>
    <origin xyz="-0.006995872672132321 0.00016351719531705557 -0.0020614117608215563" rpy="0 0 0"/>
    <mass value="1.5793453539076083"/>
    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
  </inertial>
  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
</link>

<link name="arm_base_rotation_servo_1">
  <inertial>
    <origin xyz="0.019999508147657045 0.010249860525163957 0.01602665316389948" rpy="0 0 0"/>
    <mass value="0.2843033831904074"/>
    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
  </inertial>
  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
</link>

<link name="arm_shoulder_link_1">
  <inertial>
    <origin xyz="-0.05439041310030922 0.019699384606440277 -0.020185957481023337" rpy="0 0 0"/>
    <mass value="0.9906249126045027"/>
    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
  </inertial>
  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
</link>

<link name="arm_elbow_servo_1">
  <inertial>
    <origin xyz="-0.016472070877660654 -0.016027204406308133 0.015286802190772275" rpy="0 0 0"/>
    <mass value="0.2843033831904074"/>
    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
  </inertial>
  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
</link>

<link name="arm_elbow_link_1">
  <inertial>
    <origin xyz="0.05832603889171534 0.015214739326452977 0.021377048894272332" rpy="0 0 0"/>
    <mass value="0.8772447501056027"/>
    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
  </inertial>
  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
</link>

<link name="arm_wrist_tilt_servo_1">
  <inertial>
    <origin xyz="0.02197013497411679 -0.016027204406307824 -0.004724364582700924" rpy="0 0 0"/>
    <mass value="0.2843033831904074"/>
    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
  </inertial>
  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
</link>

<link name="arm_wrist_link_1">
  <inertial>
    <origin xyz="0.02004856305995592 0.01680964179048719 -0.017145371524283942" rpy="0 0 0"/>
    <mass value="0.2392168278135931"/>
    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
  </inertial>
  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
</link>

<link name="arm_wrist_roll_servo_1">
  <inertial>
    <origin xyz="-0.018454007185755128 0.01599816538563275 0.002254236765901807" rpy="0 0 0"/>
    <mass value="0.2799142523131049"/>
    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
  </inertial>
  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
</link>

<link name="arm_gripper_1">
  <inertial>
    <origin xyz="0.01931093722742444 0.012976580613095201 -0.02252356144231421" rpy="0 0 0"/>
    <mass value="0.44698022927880193"/>
    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
  </inertial>
  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
</link>

<link name="arm_gripper_servo_1">
  <inertial>
    <origin xyz="0.02230864527990775 -0.012507702080551863 0.010382401144092585" rpy="0 0 0"/>
    <mass value="0.2843033831904074"/>
    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
  </inertial>
  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
</link>

<link name="arm_jaw_1">
  <inertial>
    <origin xyz="0.009963247508557482 -0.005399256834318277 -0.0350732340426807" rpy="0 0 0"/>
    <mass value="0.1586808414280307"/>
    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
  </inertial>
  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
</link>

<link name="wheel_2_servo_mount_1">
  <inertial>
    <origin xyz="0.02008720708501506 0.005194165504908602 0.023611185488475222" rpy="0 0 0"/>
    <mass value="0.14423806644766202"/>
    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
  </inertial>
  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
</link>

<link name="wheel_2_servo_1">
  <inertial>
    <origin xyz="0.01694649715310338 -0.008868266134855404 0.004818511002890873" rpy="0 0 0"/>
    <mass value="0.27778201352216375"/>
    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
  </inertial>
  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
</link>

<link name="wheel_2_mount_1">
  <inertial>
    <origin xyz="0.002761537077926729 -0.004783267498813332 2.924250909301651e-08" rpy="0 0 0"/>
    <mass value="0.1235708646349694"/>
    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
  </inertial>
  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
</link>

<link name="wheel_1_servo_mount_1">
  <inertial>
    <origin xyz="0.015077704264357256 0.020007007512406055 0.023639672297346263" rpy="0 0 0"/>
    <mass value="0.13962178083501173"/>
    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
  </inertial>
  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
</link>

<link name="wheel_3_servo_mount_1">
  <inertial>
    <origin xyz="0.009786475782040463 -0.023060277055295897 0.023639672305545072" rpy="0 0 0"/>
    <mass value="0.13962178077674334"/>
    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
  </inertial>
  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
</link>

<link name="wheel_1_servo_1">
  <inertial>
    <origin xyz="-0.01615356925227894 -0.010250257481275697 -0.0196985266925957" rpy="0 0 0"/>
    <mass value="0.2777820135235829"/>
    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
  </inertial>
  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
</link>

<link name="wheel_2_1">
  <inertial>
    <origin xyz="0.0076869906741244415 -0.013315239263322176 -3.569652341078866e-08" rpy="0 0 0"/>
    <mass value="1.3542854082324305"/>
    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
  </inertial>
  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
</link>

<link name="wheel_1_mount_1">
  <inertial>
    <origin xyz="-0.005523041448499452 -2.6264806006536055e-07 -2.739999609667476e-08" rpy="0 0 0"/>
    <mass value="0.1235708646349694"/>
    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
  </inertial>
  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
</link>

<link name="wheel_1_1">
  <inertial>
    <origin xyz="-0.015375154398151722 -3.713324343444975e-07 4.96189572624095e-08" rpy="0 0 0"/>
    <mass value="1.3542854082324305"/>
    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
  </inertial>
  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
</link>

<link name="wheel_3_servo_1">
  <inertial>
    <origin xyz="0.016924311610676576 0.008880942455673072 -0.019715933164635324" rpy="0 0 0"/>
    <mass value="0.27778201352216375"/>
    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
  </inertial>
  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
</link>

<link name="wheel_3_mount_1">
  <inertial>
    <origin xyz="0.0027617438821473106 0.004783233958687821 -4.149250187150677e-07" rpy="0 0 0"/>
    <mass value="0.1235708646349694"/>
    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
  </inertial>
  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
</link>

<link name="wheel_3_1">
  <inertial>
    <origin xyz="0.007687366105215164 0.013315108366428866 -2.9516542626555065e-07" rpy="0 0 0"/>
    <mass value="1.3542854082324305"/>
    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
  </inertial>
  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
</link>

<link name="orin_1">
  <inertial>
    <origin xyz="-0.029980490358262297 0.0464029204059553 0.010403436076930409" rpy="0 0 0"/>
    <mass value="0.4488469641841115"/>
    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
  </inertial>
  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
</link>

<link name="hex_2_1">
  <inertial>
    <origin xyz="4.7595823970958406e-07 1.0917212767830309e-07 0.023749588239174533" rpy="0 0 0"/>
    <mass value="0.010542792246366119"/>
    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
  </inertial>
  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
</link>

<link name="hex_1_1">
  <inertial>
    <origin xyz="4.7595823871038334e-07 1.091721259643963e-07 0.02374958823917567" rpy="0 0 0"/>
    <mass value="0.010542792246366608"/>
    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
  </inertial>
  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
</link>

<link name="hex_3_1">
  <inertial>
    <origin xyz="4.75958236510754e-07 1.0917213436045792e-07 0.02374958823917557" rpy="0 0 0"/>
    <mass value="0.010542792246365427"/>
    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
  </inertial>
  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
</link>

<link name="usb_pd_mount_1">
  <inertial>
    <origin xyz="0.010000475958207022 0.0004326566628734508 0.0019456085606616186" rpy="0 0 0"/>
    <mass value="0.0531436807920926"/>
    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
  </inertial>
  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
</link>

<link name="imu_1">
  <inertial>
    <origin xyz="0.06781047595825142 -0.18667989082754813 -0.05582174509415696" rpy="0 0 0"/>
    <mass value="0.007606013634323334"/>
    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
  </inertial>
  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
</link>

<link name="right_baseus_mount_v1_1">
  <inertial>
    <origin xyz="0.030000475958235424 -0.001615215494018607 0.02249958823918214" rpy="0 0 0"/>
    <mass value="0.08330068022697495"/>
    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
  </inertial>
  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
</link>

<link name="orin_mount_1">
  <inertial>
    <origin xyz="2.0497499575110276 -2.2977024330916964 -0.046268308453258196" rpy="0 0 0"/>
    <mass value="0.0924663763130813"/>
    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
  </inertial>
  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
</link>

<link name="arm_base_1">
  <inertial>
    <origin xyz="-0.03974858368444226 0.039996910443979204 0.02186511196271025" rpy="0 0 0"/>
    <mass value="1.2829039880853146"/>
    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
  </inertial>
  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
</link>

<link name="imu_mount_1">
  <inertial>
    <origin xyz="4.75958241134551e-07 -0.019999890827550094 0.001122411548390087" rpy="0 0 0"/>
    <mass value="0.011661793388699252"/>
    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
  </inertial>
  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
</link>

<link name="left_baseus_mount_v1_1">
  <inertial>
    <origin xyz="0.03000047595756065 0.0023725829674189763 0.021843717241236973" rpy="0 0 0"/>
    <mass value="0.060119830422065"/>
    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
  </inertial>
  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
</link>

<link name="baseus_pack_v1_1">
  <inertial>
    <origin xyz="4.759582244023841e-07 0.07750010917246258 0.022499588239177876" rpy="0 0 0"/>
    <mass value="2.7975020361255445"/>
    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
  </inertial>
  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
</link>

<link name="hex_8_1">
  <inertial>
    <origin xyz="4.759582355809422e-07 1.0917214786354545e-07 0.022749588239176638" rpy="0 0 0"/>
    <mass value="0.010098885204413197"/>
    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
  </inertial>
  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
</link>

<link name="hex_4_1">
  <inertial>
    <origin xyz="4.7595823132046133e-07 1.0917215581551787e-07 0.02374958823917601" rpy="0 0 0"/>
    <mass value="0.010542792246365427"/>
    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
  </inertial>
  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
</link>
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

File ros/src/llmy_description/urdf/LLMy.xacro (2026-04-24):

<?xml version="1.0" ?>
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
<robot name="llmy_root" xmlns:xacro="http://www.ros.org/wiki/xacro">

  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
  <xacro:arg name="use_sim" default="true"/>

  <xacro:include filename="$(find llmy_description)/urdf/materials.xacro" />
  <xacro:if value="$(arg use_sim)">
    <xacro:include filename="$(find llmy_description)/urdf/LLMy.ros2control" />
    <xacro:include filename="$(find llmy_description)/urdf/LLMy.gazebo" />
  </xacro:if>
  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
  <link name="base_link">
    <inertial>
      <origin xyz="-0.003179 -0.000009 0.005401" rpy="0 0 0"/>
      <mass value="2.227457140108448"/>
      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
    </inertial>
    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
  </link>

  <link name="right_motor_mount_1">
    <inertial>
      <origin xyz="0.023782 0.003969 0.015577" rpy="0 0 0"/>
      <mass value="0.19524814724461273"/>
      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
    </inertial>
    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
  </link>

  <link name="right_motor_1">
    <inertial>
      <origin xyz="-0.007742 -0.010688 -0.004446" rpy="0 0 0"/>
      <mass value="0.06550661857714346"/>
      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
    </inertial>
    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
  </link>

  <link name="wheel_right_1">
    <inertial>
      <origin xyz="-0.000000 0.003281 0.000000" rpy="0 0 0"/>
      <mass value="0.47698614111454785"/>
      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
    </inertial>
    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
  </link>

  <link name="left_motor_mount_1">
    <inertial>
      <origin xyz="0.023783 -0.003969 0.015577" rpy="0 0 0"/>
      <mass value="0.19524842528531677"/>
      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
    </inertial>
    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
  </link>

  <link name="left_motor_1">
    <inertial>
      <origin xyz="0.007701 0.010688 -0.004446" rpy="0 0 0"/>
      <mass value="0.06550661857714346"/>
      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
    </inertial>
    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
  </link>

  <link name="wheel_left_1">
    <inertial>
      <origin xyz="0.000000 -0.003281 0.000000" rpy="0 0 0"/>
      <mass value="0.47698614111454785"/>
      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
    </inertial>
    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
  </link>

  <link name="right_caster_1">
    <inertial>
      <origin xyz="-0.000000 0.007747 -0.008951" rpy="0 0 0"/>
      <mass value="0.04903387471960177"/>
      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
    </inertial>
    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
  </link>

  <link name="left_caster_1">
    <inertial>
      <origin xyz="-0.000000 -0.007747 -0.008951" rpy="0 0 0"/>
      <mass value="0.04903387471960177"/>
      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
    </inertial>
    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
  </link>

  <link name="right_baseus_mount_v1_1">
    <inertial>
      <origin xyz="0.019691 -0.001860 0.023385" rpy="0 0 0"/>
      <mass value="0.0655308096957003"/>
      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
    </inertial>
    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
  </link>

  <link name="left_baseus_mount_v1_1">
    <inertial>
      <origin xyz="0.019691 0.001860 0.023385" rpy="0 0 0"/>
      <mass value="0.06553077893811926"/>
      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
    </inertial>
    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
  </link>

  <link name="llmy_lidar_base_v1_1">
    <inertial>
      <origin xyz="0.015962 -0.073645 -0.015094" rpy="0 0 0"/>
      <mass value="0.3979913592232491"/>
      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
    </inertial>
    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
  </link>

  <link name="lidar_1">
    <inertial>
      <origin xyz="-0.021415 -0.021595 0.014018" rpy="0 0 0"/>
      <mass value="0.2536750002862165"/>
      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
    </inertial>
    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
  </link>

  <link name="frame_short_right">
    <inertial>
      <origin xyz="-0.000000 0.000000 0.037500" rpy="0 0 0"/>
      <mass value="0.10216504467841848"/>
      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
    </inertial>
    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
  </link>

  <link name="frame_short_left">
    <inertial>
      <origin xyz="-0.000000 -0.000000 0.037500" rpy="0 0 0"/>
      <mass value="0.10216504467841848"/>
      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
    </inertial>
    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
  </link>

  <link name="frame_tall_bl">
    <inertial>
      <origin xyz="-0.000016 0.000013 0.001354" rpy="0 0 0"/>
      <mass value="0.4366746675159977"/>
      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
    </inertial>
    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
  </link>

  <link name="frame_tall_br">
    <inertial>
      <origin xyz="-0.000016 0.000013 0.001354" rpy="0 0 0"/>
      <mass value="0.4366746675159977"/>
      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
    </inertial>
    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
  </link>

  <link name="frame_tall_fr">
    <inertial>
      <origin xyz="-0.000016 0.000013 0.001354" rpy="0 0 0"/>
      <mass value="0.4366746675159977"/>
      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
    </inertial>
    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
  </link>
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

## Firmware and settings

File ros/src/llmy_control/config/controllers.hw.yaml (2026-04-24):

# Controllers for LLMy hardware
controller_manager:
  ros__parameters:
    update_rate: 50  # Hz
    use_sim_time: false

    joint_state_broadcaster:
      type: joint_state_broadcaster/JointStateBroadcaster

    diff_drive_controller:
      type: diff_drive_controller/DiffDriveController

    arm_controller:
      type: position_controllers/JointGroupPositionController

    arm_trajectory_controller:
      type: joint_trajectory_controller/JointTrajectoryController

    head_controller:
      type: position_controllers/JointGroupPositionController

arm_controller:
  ros__parameters:
    joints: ["1","2","3","4","5","6"]

    command_interfaces:
      - position

    state_interfaces:
      - position

    open_loop_control: true

arm_trajectory_controller:
  ros__parameters:
    joints: ["1","2","3","4","5","6"]

    command_interfaces:
      - position

    state_interfaces:
      - position
      - velocity

    open_loop_control: true
    allow_partial_joints_goal: false
    allow_integration_in_goal_trajectories: true

head_controller:
  ros__parameters:
    joints: ["tilt"]

    command_interfaces:
      - position

    state_interfaces:
      - position

    open_loop_control: true

diff_drive_controller:
  ros__parameters:
    # Wheel joints
    # Motor IDs: 1=right, 2=left
    left_wheel_names: ['left_wheel_joint']
    right_wheel_names: ['right_wheel_joint']

    # Robot geometry
    wheel_separation: 0.20381  # Distance between left and right wheels (m)
    wheel_radius: 0.03725        # Wheel radius (m)

    # Wheel separation multiplier for calibration
    wheel_separation_multiplier: 1.0

    # Frames
    odom_frame_id: odom
    base_frame_id: base_footprint
    pose_covariance_diagonal: [0.001, 0.001, 0.001, 0.001, 0.001, 0.01]
    twist_covariance_diagonal: [0.001, 0.001, 0.001, 0.001, 0.001, 0.01]

    # TF publishing
    enable_odom_tf: true
    publish_rate: 50.0

    # Command timeout
    cmd_vel_timeout: 0.5

    # Velocity limits
    linear.x.has_velocity_limits: true
    linear.x.max_velocity: 0.5
    linear.x.min_velocity: -0.5
    linear.x.has_acceleration_limits: true
    linear.x.max_acceleration: 0.5

    angular.z.has_velocity_limits: true
    angular.z.max_velocity: 1.5
    angular.z.min_velocity: -1.5
    angular.z.has_acceleration_limits: true
    angular.z.max_acceleration: 1.5

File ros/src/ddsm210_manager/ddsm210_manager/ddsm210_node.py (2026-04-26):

#!/usr/bin/env python3
"""ROS2 node for Waveshare DDSM210 direct drive servo motors.

Config-driven: define motor IDs, joint names, direction multipliers,
and index mapping in YAML. Each motor gets its own serial port to avoid
TX line conflicts on the UART bus.
"""

import math
import rclpy
from rclpy.node import Node
from rclpy.qos import QoSProfile, ReliabilityPolicy, HistoryPolicy
from std_msgs.msg import Float64MultiArray
from sensor_msgs.msg import JointState

from .ddsm210 import (
    DDSM210, MODE_VELOCITY, MODE_POSITION,
    MIN_SPEED_RAW, MAX_SPEED_RAW, ENCODER_TICKS,
)


class DDSM210Node(Node):
    def __init__(self):
        super().__init__('ddsm210_node')
        self.get_logger().info("=== DDSM210 Motor Manager Starting ===")

        self._declare_and_load_params()
        self._connect()
        self._initialize_motors()
        self._setup_ros()
        self._log_startup()

    # -- parameter loading ----------------------------------------------------

    def _declare_and_load_params(self):
        self.declare_parameter("ports", ["/dev/ttyUSB0"])
        self.declare_parameter("baud", 115200)
        self.declare_parameter("command_rate", 50.0)
        self.declare_parameter("telemetry_rate", 50.0)
        self.declare_parameter("joint_states_topic", "/motor_manager/joint_states")
        self.declare_parameter("command_topic", "/motor_manager/base_cmd")
        self.declare_parameter("total_joints", 0)
        self.declare_parameter("mode", "velocity")
        self.declare_parameter("accel_time", 0)
        self.declare_parameter("max_rpm", 210)  # hardware max is 210 RPM

        self.declare_parameter("motor_ids", [1, 2])
        self.declare_parameter("joint_names", ["right_wheel_joint", "left_wheel_joint"])
        self.declare_parameter("direction", [1, -1])
        self.declare_parameter("command_indices", [0, 1])
        self.declare_parameter("state_indices", [0, 1])
        self.declare_parameter("speed_scale", 1.0)

        get = self.get_parameter
        self.ports = list(get("ports").get_parameter_value().string_array_value)
        self.baud = get("baud").get_parameter_value().integer_value
        self.command_rate = get("command_rate").get_parameter_value().double_value
        self.telemetry_rate = get("telemetry_rate").get_parameter_value().double_value
        self.joint_states_topic = get("joint_states_topic").get_parameter_value().string_value
        self.command_topic = get("command_topic").get_parameter_value().string_value
        self.total_joints = get("total_joints").get_parameter_value().integer_value
        self.mode = get("mode").get_parameter_value().string_value
        self.accel_time = get("accel_time").get_parameter_value().integer_value
        self.max_rpm = get("max_rpm").get_parameter_value().integer_value

        self.motor_ids = list(get("motor_ids").get_parameter_value().integer_array_value)
        self.joint_names = list(get("joint_names").get_parameter_value().string_array_value)
        self.direction = list(get("direction").get_parameter_value().integer_array_value)
        self.command_indices = list(get("command_indices").get_parameter_value().integer_array_value)
        self.state_indices = list(get("state_indices").get_parameter_value().integer_array_value)
        self.speed_scale = get("speed_scale").get_parameter_value().double_value

        n = len(self.motor_ids)
        for field, name in [(self.joint_names, "joint_names"),
                            (self.direction, "direction"),
                            (self.command_indices, "command_indices"),
                            (self.state_indices, "state_indices")]:
            if len(field) != n:
                raise ValueError(f"{name} has {len(field)} entries, expected {n}")

        # Ports: one per motor, or one shared by all
        if len(self.ports) == 1:
            self.ports = self.ports * n  # expand single port to all motors
        elif len(self.ports) != n:
            raise ValueError(
                f"ports has {len(self.ports)} entries, expected 1 or {n}")

        # Auto-calculate total_joints if not set
        if self.total_joints <= 0 and self.state_indices:
            self.total_joints = max(self.state_indices) + 1

        self.motor_count = n

    # -- connection and init --------------------------------------------------

    def _connect(self):
        # One DDSM210 driver per unique port
        self._port_drivers: dict[str, DDSM210] = {}
        self._motor_driver: dict[int, DDSM210] = {}

        for i, mid in enumerate(self.motor_ids):
            port = self.ports[i]
            if port not in self._port_drivers:
                driver = DDSM210(port, self.baud)
                self._port_drivers[port] = driver
                self.get_logger().info(f"Connected to {port} @ {self.baud}")
            self._motor_driver[mid] = self._port_drivers[port]

        # Verify connectivity
        mode_names = {0x00: "open_loop", 0x02: "velocity", 0x03: "position"}
        for i, mid in enumerate(self.motor_ids):
            mode = self._motor_driver[mid].get_mode(mid)
            if mode is not None:
                self.get_logger().info(
                    f"  Motor {mid} ({self.ports[i]}): ONLINE "
                    f"(mode={mode_names.get(mode, hex(mode))})")
            else:
                self.get_logger().warn(
                    f"  Motor {mid} ({self.ports[i]}): no response")

    def _initialize_motors(self):
        mode_val = MODE_VELOCITY if self.mode == "velocity" else MODE_POSITION
        mode_name = "velocity" if self.mode == "velocity" else "position"

        self.get_logger().info(f"Setting motors to {mode_name} loop mode...")
        for mid in self.motor_ids:
            resp = self._motor_driver[mid].set_mode(mid, mode_val)
            if resp is not None:
                self.get_logger().info(f"  Motor {mid}: mode set OK")
            else:
                self.get_logger().warn(f"  Motor {mid}: mode set got no response")

        self._last_commands: list[float] = []

    # -- ROS setup ------------------------------------------------------------

    def _setup_ros(self):
        cmd_qos = QoSProfile(
            history=HistoryPolicy.KEEP_LAST,
            depth=10,
            reliability=ReliabilityPolicy.BEST_EFFORT)

        self._cmd_sub = self.create_subscription(
            Float64MultiArray, self.command_topic,
            self._handle_command, cmd_qos)
        self.get_logger().info(f"  Subscriber: {self.command_topic}")

        self._state_pub = self.create_publisher(
            JointState, self.joint_states_topic, 10)
        self.get_logger().info(f"  Publisher: {self.joint_states_topic}")

        self._telemetry_timer = self.create_timer(
            1.0 / self.telemetry_rate, self._publish_telemetry)
        self.get_logger().info(f"  Telemetry timer: {self.telemetry_rate} Hz")

    # -- command handling -----------------------------------------------------

    def _handle_command(self, msg: Float64MultiArray):
        self._cmd_rx_count = getattr(self, "_cmd_rx_count", 0) + 1
        max_idx = max(self.command_indices)
        if len(msg.data) <= max_idx:
            self.get_logger().warn(
                f"Command too short: need index {max_idx}, got length {len(msg.data)}")
            return

        values = [msg.data[ci] for ci in self.command_indices]

        # Log raw values every Nth message, and every time they change.
        changed = (len(self._last_commands) != len(values)
                   or any(abs(a - b) >= 1e-6
                          for a, b in zip(values, self._last_commands)))
        if changed or self._cmd_rx_count % 100 == 1:
            self.get_logger().info(
                f"cmd rx #{self._cmd_rx_count}: raw={list(msg.data)} "
                f"picked={values} changed={changed}")

        # Skip if unchanged
        if not changed:
            return
        self._last_commands = list(values)

        for i, mid in enumerate(self.motor_ids):
            value = values[i] * self.direction[i]
            driver = self._motor_driver[mid]

            if self.mode == "velocity":
                rpm = value * self.speed_scale * 60.0 / (2.0 * math.pi)
                self.get_logger().info(
                    f"  -> motor {mid}: {value:+.3f} rad/s (dir={self.direction[i]}) => {rpm:+.1f} RPM")
                self._send_velocity(driver, mid, value)
            else:
                self.get_logger().info(
                    f"  -> motor {mid}: {value:+.3f} rad (dir={self.direction[i]})")
                self._send_position(driver, mid, value)

    def _send_velocity(self, driver: DDSM210, motor_id: int, rad_per_sec: float):
        """Convert rad/s to DDSM210 speed units (0.1 RPM) and send."""
        rpm = rad_per_sec * self.speed_scale * 60.0 / (2.0 * math.pi)
        rpm_x10 = int(rpm * 10.0)
        # Cap at the user-configured max (converted to 0.1-RPM units), within hardware bounds.
        user_cap = min(abs(self.max_rpm) * 10, MAX_SPEED_RAW)
        clamped = max(-user_cap, min(user_cap, rpm_x10))
        resp = driver.set_velocity(motor_id, clamped, self.accel_time)
        if resp is None:
            self.get_logger().warn(
                f"     motor {motor_id}: no serial response to set_velocity({clamped})")
        else:
            self.get_logger().debug(
                f"     motor {motor_id}: wrote {clamped} (feedback={resp})")

    def _send_position(self, driver: DDSM210, motor_id: int, angle_rad: float):
        """Convert radians to DDSM210 position units (0-32767) and send."""
        angle = angle_rad % (2.0 * math.pi)
        pos = int(angle / (2.0 * math.pi) * 32767)
        pos = max(0, min(32767, pos))
        driver.set_position(motor_id, pos)

    # -- telemetry ------------------------------------------------------------

    def _publish_telemetry(self):
        names = [""] * self.total_joints
        positions = [0.0] * self.total_joints
        velocities = [0.0] * self.total_joints

        for i, mid in enumerate(self.motor_ids):
            state_idx = self.state_indices[i]
            direction = self.direction[i]
            driver = self._motor_driver[mid]

            odom = driver.get_odometry(mid)
            if odom is None:
                continue

            mileage = odom['mileage_laps']
            enc_pos = odom['position']  # 0-65535 = 0-360 deg

            fractional_rad = (enc_pos / ENCODER_TICKS) * 2.0 * math.pi
            total_rad = mileage * 2.0 * math.pi + fractional_rad

            names[state_idx] = self.joint_names[i]
            positions[state_idx] = total_rad * direction
            velocities[state_idx] = 0.0

        if not any(n for n in names):
            return

        msg = JointState()
        msg.header.stamp = self.get_clock().now().to_msg()
        msg.name = names
        msg.position = positions
        msg.velocity = velocities
        self._state_pub.publish(msg)

    # -- startup log ----------------------------------------------------------

    def _log_startup(self):
        self.get_logger().info("=== DDSM210 Motor Manager Ready ===")
        unique_ports = list(self._port_drivers.keys())
        self.get_logger().info(f"  Serial ports: {unique_ports}")
        for i, mid in enumerate(self.motor_ids):
            self.get_logger().info(
                f"  Motor {mid}: {self.joint_names[i]} | "
                f"port={self.ports[i]} | "
                f"dir={self.direction[i]} | "
                f"cmd_idx={self.command_indices[i]} | "
                f"state_idx={self.state_indices[i]}")


def main(args=None):
    rclpy.init(args=args)
    try:
        node = DDSM210Node()
        rclpy.spin(node)
    except KeyboardInterrupt:
        pass
    except Exception as e:
        print(f"Error: {e}")
    finally:
        if rclpy.ok():
            rclpy.shutdown()


if __name__ == '__main__':
    main()

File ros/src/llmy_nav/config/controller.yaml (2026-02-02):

# MPPI Controller Configuration for LLMy Robot
# Model Predictive Path Integral controller for differential drive

controller_server:
  ros__parameters:
    enable_stamped_cmd_vel: true
    controller_frequency: 20.0
    min_x_velocity_threshold: 0.001
    min_y_velocity_threshold: 0.5       # Not used for diff drive
    min_theta_velocity_threshold: 0.001
    progress_checker_plugins: ["progress_checker"]
    goal_checker_plugins: ["goal_checker"]
    controller_plugins: ["FollowPath"]

    progress_checker:
      plugin: "nav2_controller::SimpleProgressChecker"
      required_movement_radius: 0.5
      movement_time_allowance: 10.0

    goal_checker:
      plugin: "nav2_controller::SimpleGoalChecker"
      xy_goal_tolerance: 0.25             # 25cm position tolerance
      yaw_goal_tolerance: 0.25            # ~14 degree orientation tolerance
      stateful: true

    FollowPath:
      plugin: "nav2_mppi_controller::MPPIController"

      # Prediction horizon: 56 steps * 0.05s = 2.8 second lookahead
      time_steps: 56
      model_dt: 0.05
      batch_size: 2000                    # Number of sampled trajectories
      vx_std: 0.2                         # Velocity sampling std dev
      vy_std: 0.0                         # Not used for diff drive
      wz_std: 0.4                         # Angular velocity sampling std dev
      vx_max: 0.5                         # Max forward velocity (m/s)
      vx_min: -0.2                        # Max reverse velocity (m/s)
      vy_max: 0.0                         # No lateral (differential drive)
      wz_max: 1.0                         # Max angular velocity (rad/s)
      iteration_count: 1
      prune_distance: 1.7
      transform_tolerance: 0.1
      temperature: 0.3
      gamma: 0.015
      motion_model: "DiffDrive"
      visualize: false
      regenerate_noises: false
      TrajectoryVisualizer:
        trajectory_step: 5
        time_step: 3
      AckermannConstraints:
        min_turning_r: 0.2
      critics: ["ConstraintCritic", "ObstaclesCritic", "GoalCritic", "GoalAngleCritic", "PathAlignCritic", "PathFollowCritic", "PathAngleCritic", "PreferForwardCritic"]

      ConstraintCritic:
        enabled: true
        cost_power: 1
        cost_weight: 4.0

      GoalCritic:
        enabled: true
        cost_power: 1
        cost_weight: 5.0
        threshold_to_consider: 1.4

      GoalAngleCritic:
        enabled: true
        cost_power: 1
        cost_weight: 3.0
        threshold_to_consider: 0.5

      PreferForwardCritic:
        enabled: true
        cost_power: 1
        cost_weight: 5.0
        threshold_to_consider: 0.5

      ObstaclesCritic:
        enabled: true
        cost_power: 1
        repulsion_weight: 0.3
        critical_weight: 20.0
        consider_footprint: false
        collision_cost: 10000.0
        collision_margin_distance: 0.1
        near_goal_distance: 0.5
        inflation_radius: 0.25            # Match inflation layer
        cost_scaling_factor: 10.0

      PathAlignCritic:
        enabled: true
        cost_power: 1
        cost_weight: 14.0
        max_path_occupancy_ratio: 0.05
        trajectory_point_step: 3
        threshold_to_consider: 0.5
        offset_from_furthest: 20
        use_path_orientations: false

      PathFollowCritic:
        enabled: true
        cost_power: 1
        cost_weight: 5.0
        offset_from_furthest: 5
        threshold_to_consider: 1.4

      PathAngleCritic:
        enabled: true
        cost_power: 1
        cost_weight: 2.0
        offset_from_furthest: 4
        threshold_to_consider: 0.5
        max_angle_to_furthest: 1.0
        mode: 0

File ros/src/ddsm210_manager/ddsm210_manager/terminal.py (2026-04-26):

#!/usr/bin/env python3
"""Interactive terminal for DDSM210 motors — no ROS required.

Usage:
    ros2 run ddsm210_manager terminal -- --port /dev/ttyUSB0
    ros2 run ddsm210_manager terminal -- --port /dev/ttyUSB0 --port /dev/ttyUSB1
"""

import argparse
import cmd
import sys

from .ddsm210 import (
    DDSM210, MODE_VELOCITY, MODE_POSITION, MODE_OPEN_LOOP,
)

MODE_NAMES = {0x00: "open_loop", 0x02: "velocity", 0x03: "position"}
MODE_VALUES = {"open_loop": MODE_OPEN_LOOP, "velocity": MODE_VELOCITY, "position": MODE_POSITION}


class DDSM210Shell(cmd.Cmd):
    intro = (
        "\n"
        "  DDSM210 Motor Terminal\n"
        "  Type 'help' for commands, 'quit' to exit.\n"
        "  All motors are braked on exit.\n"
    )
    prompt = "ddsm210> "

    def __init__(self, drivers: dict[str, DDSM210], ports: list[str]):
        super().__init__()
        self.drivers = drivers          # port -> DDSM210
        self.ports = ports              # ordered list of ports
        self.motor_port: dict[int, str] = {}   # motor_id -> port (learned from scan/ping)
        self.active_motors: set[int] = set()

    # -- helpers --------------------------------------------------------------

    def _parse_id(self, arg: str) -> int | None:
        try:
            return int(arg)
        except ValueError:
            print(f"  Invalid motor ID: {arg}")
            return None

    def _get_driver(self, motor_id: int) -> DDSM210 | None:
        """Get the driver for a motor. If not yet known, try all ports."""
        if motor_id in self.motor_port:
            return self.drivers[self.motor_port[motor_id]]

        # Try each port to find this motor
        for port, driver in self.drivers.items():
            mode = driver.get_mode(motor_id)
            if mode is not None:
                self.motor_port[motor_id] = port
                return driver

        print(f"  Motor {motor_id}: not found on any port")
        return None

    def _brake_all(self):
        for mid in list(self.active_motors):
            driver = self._get_driver(mid)
            if driver:
                try:
                    driver.brake(mid)
                except Exception:
                    pass
        self.active_motors.clear()

    # -- commands -------------------------------------------------------------

    def do_ports(self, _arg):
        """ports    List connected serial ports."""
        for i, port in enumerate(self.ports):
            print(f"  [{i}] {port}")
        if self.motor_port:
            print("  Known motor assignments:")
            for mid, port in sorted(self.motor_port.items()):
                print(f"    Motor {mid} -> {port}")

    def do_ping(self, arg):
        """ping <id>    Check if motor is online (searches all ports)."""
        mid = self._parse_id(arg)
        if mid is None:
            return
        for port, driver in self.drivers.items():
            mode = driver.get_mode(mid)
            if mode is not None:
                self.motor_port[mid] = port
                print(f"  Motor {mid}: ONLINE on {port} "
                      f"(mode={MODE_NAMES.get(mode, hex(mode))})")
                return
        print(f"  Motor {mid}: no response on any port")

    def do_scan(self, arg):
        """scan [max_id]    Scan all ports for motors (default: IDs 1-10)."""
        max_id = int(arg) if arg.strip() else 10
        found = []
        for port, driver in self.drivers.items():
            for mid in range(1, max_id + 1):
                mode = driver.get_mode(mid)
                if mode is not None:
                    self.motor_port[mid] = port
                    found.append((mid, port))
                    print(f"  Motor {mid}: ONLINE on {port} "
                          f"(mode={MODE_NAMES.get(mode, hex(mode))})")
        if not found:
            print("  No motors found.")
        else:
            print(f"  Found {len(found)} motor(s)")

    def do_mode(self, arg):
        """mode <id> <velocity|position|open_loop>    Set motor operating mode."""
        parts = arg.split()
        if len(parts) != 2:
            print("  Usage: mode <id> <velocity|position|open_loop>")
            return
        mid = self._parse_id(parts[0])
        if mid is None:
            return
        mode_str = parts[1].lower()
        if mode_str not in MODE_VALUES:
            print(f"  Invalid mode: {mode_str}. Use: velocity, position, open_loop")
            return
        driver = self._get_driver(mid)
        if not driver:
            return
        resp = driver.set_mode(mid, MODE_VALUES[mode_str])
        if resp:
            print(f"  Motor {mid}: mode set to {mode_str}")
        else:
            print(f"  Motor {mid}: no response (mode switch may not reply)")

    def do_speed(self, arg):
        """speed <id> <rpm>    Set velocity in RPM (-210 to 210). Use 0 to stop."""
        parts = arg.split()
        if len(parts) != 2:
            print("  Usage: speed <id> <rpm>")
            return
        mid = self._parse_id(parts[0])
        if mid is None:
            return
        try:
            rpm = float(parts[1])
        except ValueError:
            print(f"  Invalid RPM: {parts[1]}")
            return
        driver = self._get_driver(mid)
        if not driver:
            return
        rpm_x10 = int(rpm * 10)
        fb = driver.set_velocity(mid, rpm_x10)
        self.active_motors.add(mid)
        if fb:
            print(f"  Motor {mid}: speed={rpm:.1f} RPM | "
                  f"fb_speed={fb['feedback1']} | "
                  f"temp={fb['temperature']}C | "
                  f"error=0x{fb['error_code']:02X}")
        else:
            print(f"  Motor {mid}: no response")

    def do_pos(self, arg):
        """pos <id> <degrees>    Set position in degrees (0-360). Requires position mode."""
        parts = arg.split()
        if len(parts) != 2:
            print("  Usage: pos <id> <degrees>")
            return
        mid = self._parse_id(parts[0])
        if mid is None:
            return
        try:
            deg = float(parts[1])
        except ValueError:
            print(f"  Invalid degrees: {parts[1]}")
            return
        driver = self._get_driver(mid)
        if not driver:
            return
        position = int((deg % 360.0) / 360.0 * 32767)
        fb = driver.set_position(mid, position)
        if fb:
            print(f"  Motor {mid}: target={deg:.1f} deg ({position}) | "
                  f"temp={fb['temperature']}C | "
                  f"error=0x{fb['error_code']:02X}")
        else:
            print(f"  Motor {mid}: no response")
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

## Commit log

2025-08-28 tested and fixed leremix_imu
    [imu_node.py]
2025-08-28 fixed camera stuff, added retry for microros firmware
    [controllers.base.yaml]
2025-08-28 fixed various issues that might have prevented ros_control from starting
    [controllers.yaml]
2025-08-28 added ros_control tag to urdf, will focus on the fact that this breaks simulation later
    [LeRemix.xacro]
2025-08-28 debug prints, servo decativated by default
2025-08-28 debugging esp32 communication
2025-08-29 fixed xbox launching, added simple tester, rewamped servo_driver
2025-09-01 added simple motor without OLED
2025-09-01 almost working movement
    [controllers.yaml]
2025-09-02 base movement working
    [controllers.base.yaml, controllers.yaml]
2025-09-03 adding tower, bastardized URDF
    [LeRemix.xacro, arm_base_1.stl, arm_base_rotation_link_cover_1.stl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]
2026-01-06 added MCP and Nav packages
    [controller.yaml, controllers.hw.yaml, robot.yaml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]
2026-01-10 properly integrated two wheel version URDF, motion works in simulation
    [LLMy.hardware.xacro, arm_base_1.stl, arm_base_rotation_link_1.stl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]
2026-01-10 removed source package
    [arm_base_1.stl, arm_base_rotation_link_1.stl, arm_base_rotation_link_cover_1.stl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]
2026-01-13 changed imu lib
    [BL_motor_1.stl, BL_wheel_1.stl, BR_motor_1.stl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]
2026-01-17 unwraped values in telemetry, adjusted incorrect wheel sepparation, changed slam_toolbox parameters
    [LLMy.hardware.xacro, LLMy.xacro, controllers.hw.yaml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]
2026-01-18 slam is finally working properly
    [LLMy.hardware.xacro, LLMy.xacro, arm_base_1.stl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]
2026-01-18 omg mcp works holy shit
    [robot.yaml, robot_hybrid.yaml]
2026-01-27 added motor_telemetry
    [servo_manager.yaml]
2026-02-02 added nav to sim
    [LLMy.hardware.xacro, LLMy.xacro, controller.yaml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]
2026-02-02 updated wheel sepparation for sim
    [controllers.sim.yaml]
2026-02-03 navigation done
    [LLMy.xacro, controllers.sim.yaml]
2026-02-03 navigation and exploration added, nav tested
    [controllers.sim.yaml]
2026-04-24 updated with new version
    [Extrusion_3_way__joint_v1__2__1.stl, Extrusion_3_way__joint_v1__2___1__1.stl, Extrusion_3_way__joint_v1__2___2__1.stl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]
2026-04-26 unignored important files
    [LLMy.xacro, arm_base_1.stl, arm_base_rotation_link_1.stl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]
